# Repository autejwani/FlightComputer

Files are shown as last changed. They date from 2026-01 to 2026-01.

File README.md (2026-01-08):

# Flight Computer Firmware

This repository contains the **C++ firmware** and hardware design files for a custom **rocket flight computer** built around a Teensy development kit. The system is designed for my L1 model rocket and emphasizes low-level control and modular sensor drivers.

All firmware is written **from scratch in C++**, with no high-level sensor abstraction libraries, to allow full control over hardware configuration, timing, and data flow.

---

## System Overview

The flight computer integrates multiple sensing, estimation, and communication subsystems to estimate vehicle state and transmit telemetry during flight.

The current implementation focuses on:
- **Altitude estimation using an Extended Kalman Filter (EKF)**
- **Low-level sensor interfacing over I2C**
- **LoRa-based telemetry**
- **Modular and scalable firmware architecture**

---

## Project Structure

```text

├── Controls/
│   ├── ekf.cpp
│   └── ekf.h
│
├── Sensing/
│   ├── imu.cpp
│   ├── imu.h
│   ├── baro.cpp
│   ├── baro.h
│   ├── mag.cpp
│   └── mag.h
│
├── Utilities/
│   ├── i2c.cpp
│   └── i2c.h
│
├── LoRa/
│   ├── transmitter.cpp
│   └── receiver.cpp
│
└── main.cpp
```
## Folder Descriptions

### **Controls**
Contains control and estimation algorithms.

- **`ekf.cpp / ekf.h`**  
  Implements an **Extended Kalman Filter (EKF)** used to estimate the vehicle’s **Z-axis state (altitude)** during flight.  
  The EKF fuses inertial and barometric measurements and is designed to be expanded to full **3-axis state estimation**.

---

### **Sensing**
Contains low-level sensor drivers, each split into a header and implementation file.

- **IMU (`imu.cpp / imu.h`)**  
  Provides accelerometer and gyroscope data for motion sensing.

- **Barometer (`baro.cpp / baro.h`)**  
  Provides pressure-based altitude measurements used by the EKF.

All sensors are configured and read at the **register level**, without relying on vendor abstraction libraries.

---

### **Utilities**
Contains reusable hardware communication helpers.

- **I2C (`i2c.cpp / i2c.h`)**  
  Implements low-level I2C read/write utilities, multi-byte transactions, and device probing.  
  This layer is shared across all sensor drivers.

---

## **LoRa**
Contains long-range wireless communication code used for flight telemetry and ground station reception.

The LoRa subsystem is designed to transmit **compact, fixed-length binary packets** for reliability, low latency, and ease of parsing on resource-constrained hardware.

---

### **Telemetry Packet Format**

Each LoRa transmission consists of a **fixed 11-byte packet** with the following structure:

| Byte Index | Field | Size (bytes) | Type | Description |
|---:|---|---|---|---|
| 0 | Packet ID | 1 | `uint8_t` | Reserved for packet type / sync|
| 1–4 | Timestamp | 4 | `uint32_t`| System timestamp in **milliseconds** |
| 5–6 | Temperature | 2 | `int16_t` | Temperature in **°C × 100** (fixed-point) |
| 7–10 | Pressure | 4 | `int32_t` | Pressure in **Pascals (Pa)** |

**Total packet size:** `11 bytes`

---

### **Encoding Details**

- **Timestamp**
  - Big-endian format
  - Represents system uptime in milliseconds
  - Used for packet ordering and time correlation

- **Temperature**
  - Signed 16-bit fixed-point value  
  - Conversion:  
    ```
    temperature (°C) = int16_value / 100.0
    ```
  - Example: `2534 → 25.34 °C`

- **Pressure**
  - Signed 32-bit integer
  - Units: **Pascals (Pa)**
  - Intended for altitude calculation and EKF validation on the ground station

---

### **`transmitter.cpp`**
Packages sensor telemetry into the fixed 11-byte binary packet and transmits it over LoRa at **915 MHz**.

Responsibilities include:
- Packing sensor values into fixed-point binary fields
- Enforcing a fixed packet length
- Periodic telemetry transmission during flight

The packet structure is intentionally minimal to:
- Reduce airtime
- Improve link reliability
- Avoid dynamic memory allocation

---

### **`receiver.cpp`**
Receives and validates incoming LoRa packets on the ground station.

Responsibilities include:
- Verifying packet length (`11 bytes`)
- Parsing binary fields into native types
- Converting fixed-point values to floating-point
- Displaying telemetry via **Serial** and **OLED**

Packets with unexpected lengths are discarded to ensure data integrity.

---

### **Design**
Contains the hardware design files for the flight computer PCB.

This includes:
- PCB layout files  
- Schematics  
- Manufacturing and fabrication outputs  

These files document the **complete electrical design** of the flight computer hardware.

---

## `main.cpp`

`main.cpp` serves as the system entry point and integrates all subsystems. It:

- Initializes I2C and sensors  
- Initializes the EKF  
- Continuously reads sensor data  
- Runs the EKF update loop  
- Monitors the **Z-axis (altitude) state estimate** in real time  
- Interfaces with the LoRa telemetry system  

---

## Design Goals

- C++ firmware for embedded flight systems  
- Register-level sensor control  
- Clear separation between sensing, utilities, control, and communication  
- EKF-based state estimation  
- Reliable long-range telemetry  
- Scalable architecture for future expansion  

---

## Build Environment

- **Language:** C++  
- **Framework:** Arduino (STM32 core)  
- **Build System:** PlatformIO  
- **Target:** Custom STM32-based flight computer hardware

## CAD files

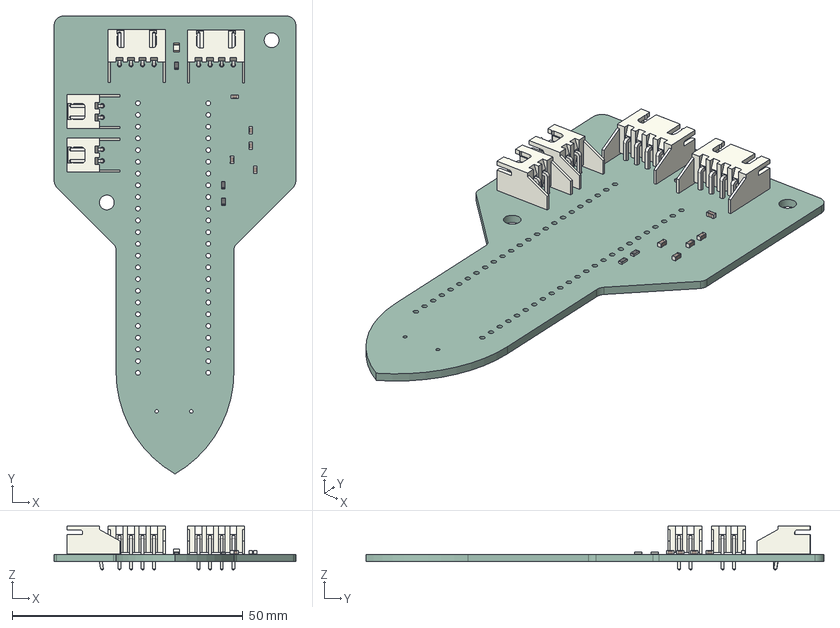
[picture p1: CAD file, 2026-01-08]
Design/AdityaFlightComputer.step
52.4 x 99.2 x 9.50 mm
JST_XH_S2B-XH-A-1_1x02_P2.50mm_Horizontal x 2
R_0603_1608Metric x 3
C_0603_1608Metric x 5
JST_XH_S4B-XH-A-1_1x04_P2.50mm_Horizontal x 2
LED_0805_2012Metric
AdityaFlightComputer_PCB

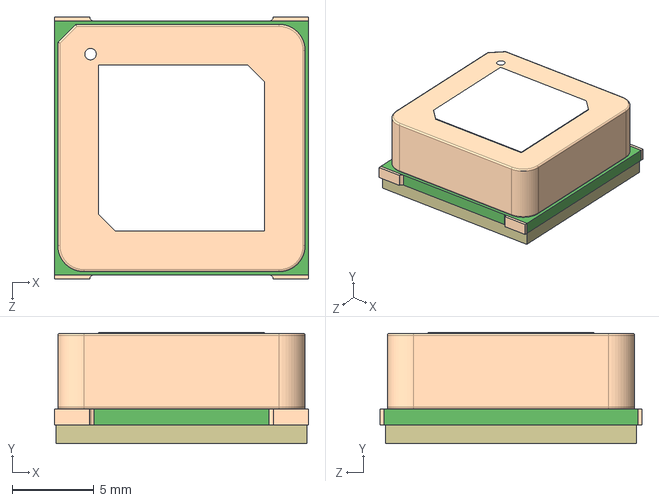
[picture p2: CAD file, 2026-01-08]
Design/Footprints/GPS/SAM-M10Q-00B.step
15.5 x 6.80 x 16.0 mm

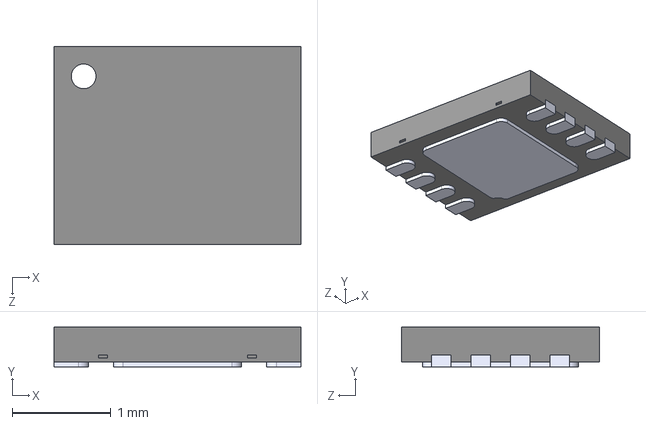
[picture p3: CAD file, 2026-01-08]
Design/Footprints/Magnetometer/MLX90397RLQ-AAA-000-SP.step
2.50 x 0.4 x 2.00 mm

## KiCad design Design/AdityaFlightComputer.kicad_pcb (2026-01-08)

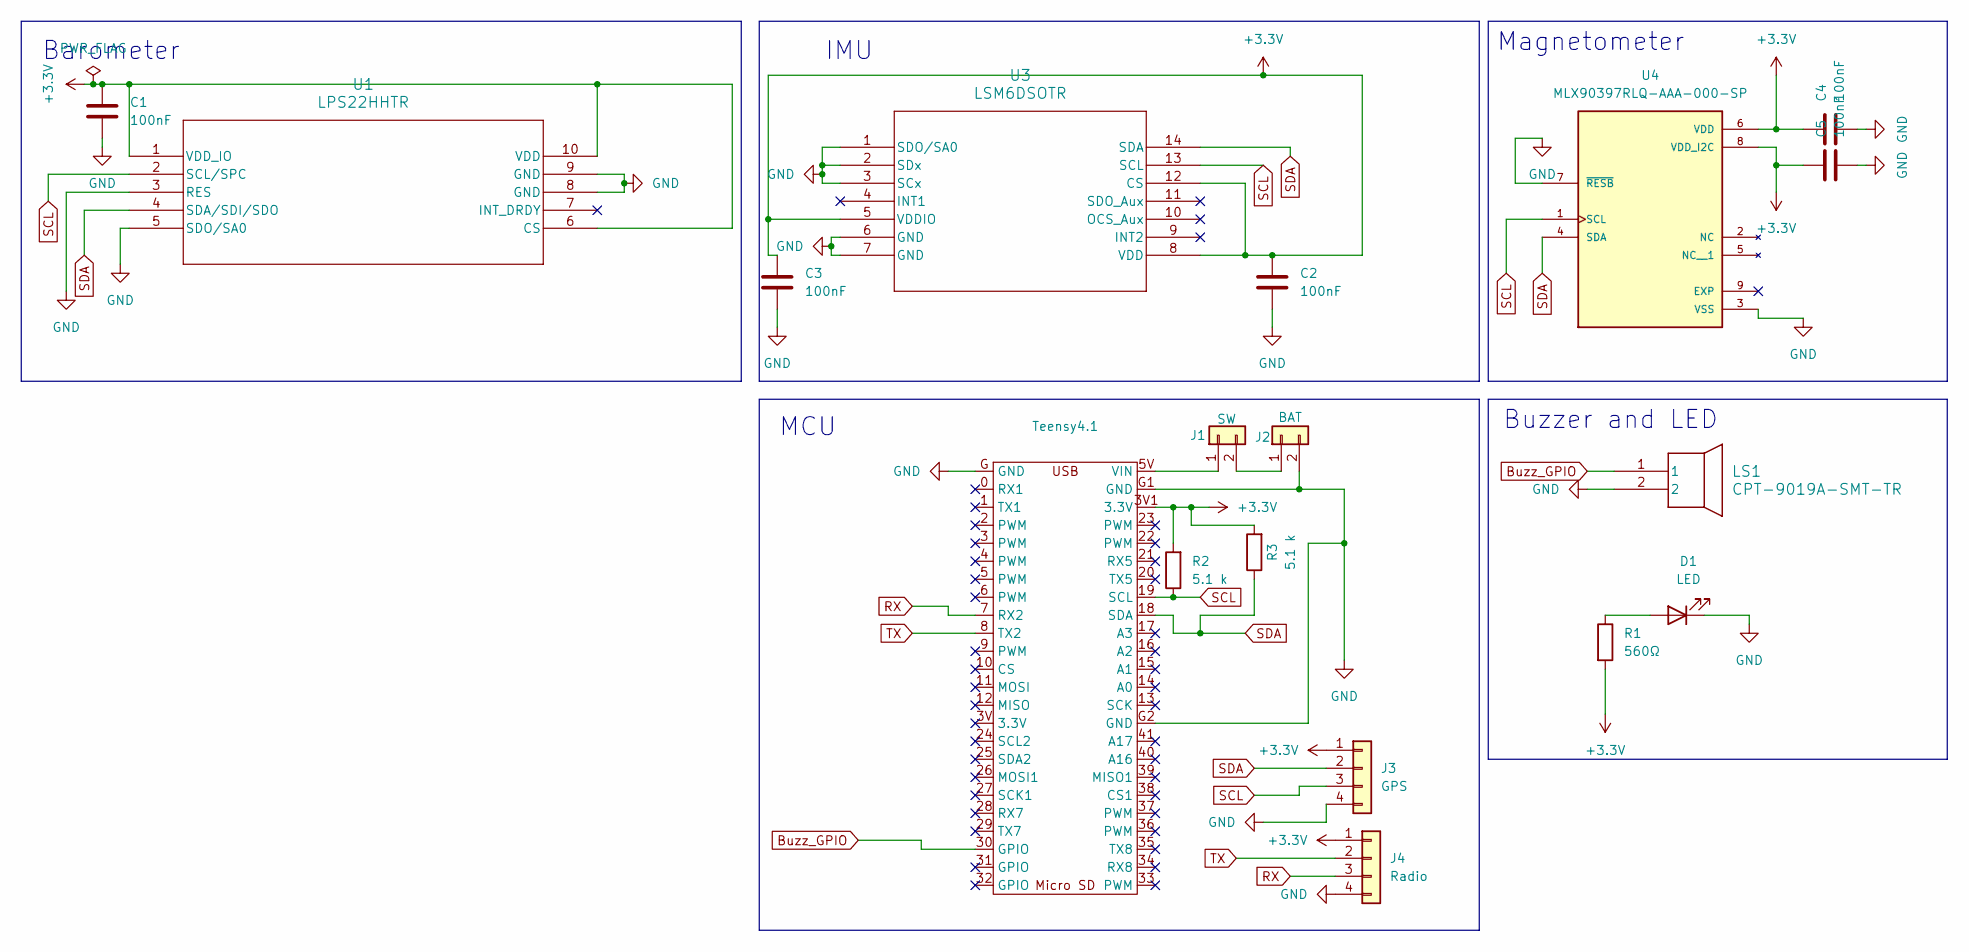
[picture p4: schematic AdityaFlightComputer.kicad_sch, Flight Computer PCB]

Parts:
C1, C2, C3, C4, C5: 100nF; C_0603_1608Metric
D1: LED; LED_0805_2012Metric
J1: SW; JST_XH_S2B-XH-A-1_1x02_P2.50mm_Horizontal
J2: BAT; JST_XH_S2B-XH-A-1_1x02_P2.50mm_Horizontal
J3: GPS; JST_XH_S4B-XH-A-1_1x04_P2.50mm_Horizontal
J4: Radio; JST_XH_S4B-XH-A-1_1x04_P2.50mm_Horizontal
LS1: CPT-9019A-SMT-TR; Adafruit_Buzzer
R1: 560Ω; R_0603_1608Metric
R2, R3: 5.1 k; R_0603_1608Metric
Teensy4.1: teensy
U1: LPS22HHTR; HLGA-10L_2X2X0P73_STM
U3: LSM6DSOTR; LGA-14L_2P5X3X0P86_STM
U4: MLX90397RLQ-AAA-000-SP; SON40P200X250X40-9N; PARTREV 002

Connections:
+3.3V: C1.1, C2.1, C3.1, C4.1, C5.1, J3.1, J4.1, R1.2, R2.2, R3.2, Teensy4.1.3V1 (3.3V), U1.1 (VDD_IO), U1.6 (CS), U1.10 (VDD), U3.5 (VDDIO), U3.8 (VDD), U3.12 (CS), U4.6 (VDD), U4.8 (VDD_I2C)
Buzz_GPIO: LS1.1, Teensy4.1.30 (GPIO)
GND: C1.2, C2.2, C3.2, C4.2, C5.2, D1.1 (K), J2.2, J3.4, J4.4, LS1.2, Teensy4.1.G (GND), Teensy4.1.G1 (GND), Teensy4.1.G2 (GND), U1.3 (RES), U1.5 (SDO/SA0), U1.8 (GND), U1.9 (GND), U3.1 (SDO/SA0), U3.2 (SDx), U3.3 (SCx), U3.6 (GND), U3.7 (GND), U4.3 (VSS), U4.7 (~RESB)
unnamed: D1.2 (A), R1.1
unnamed: J1.1, Teensy4.1.5V (VIN)
unnamed: J1.2, J2.1
RX: J4.3, Teensy4.1.7 (RX2)
SCL: J3.3, R2.1, Teensy4.1.19 (SCL), U1.2 (SCL/SPC), U3.13 (SCL), U4.1 (SCL)
SDA: J3.2, R3.1, Teensy4.1.18 (SDA), U1.4 (SDA/SDI/SDO), U3.14 (SDA), U4.4 (SDA)
TX: J4.2, Teensy4.1.8 (TX2)

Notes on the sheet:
Buzzer and LED
MCU
Magnetometer
IMU
Barometer

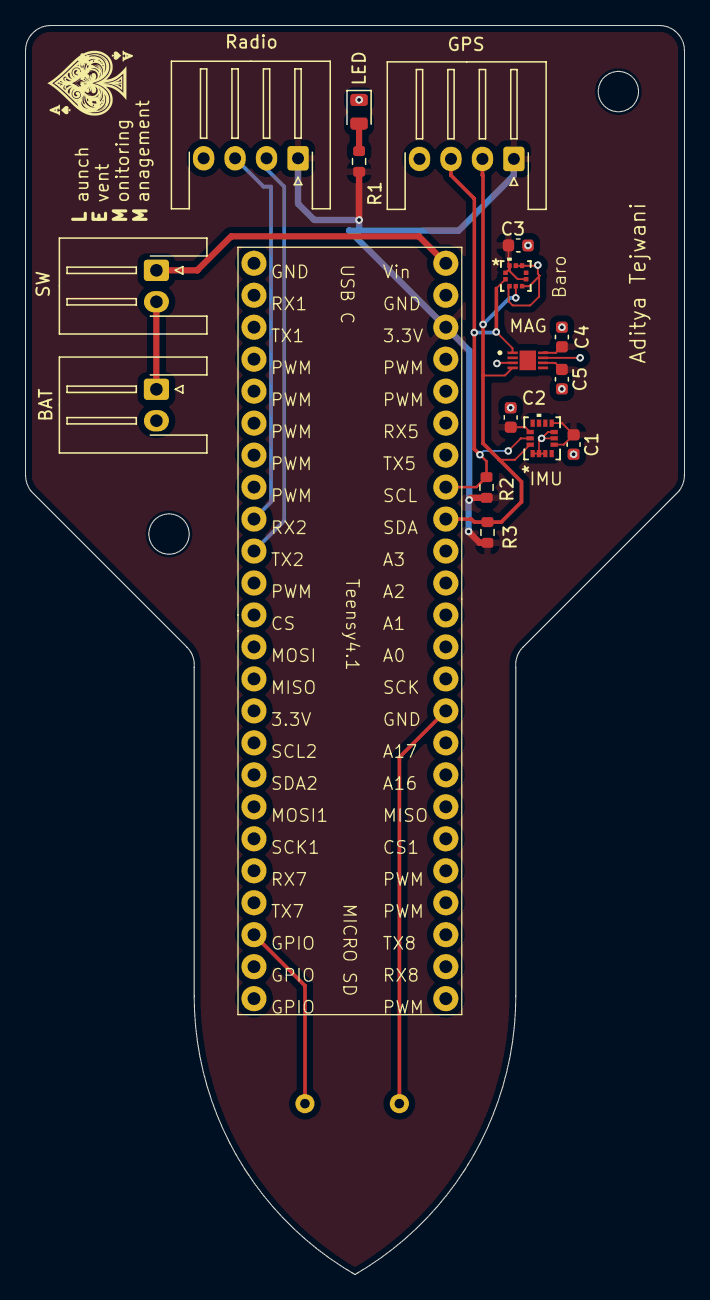
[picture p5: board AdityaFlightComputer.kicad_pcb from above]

Board: 2 copper layers, 52.4 x 99.2 mm, 18 parts (1 on the bottom side), 10 nets.

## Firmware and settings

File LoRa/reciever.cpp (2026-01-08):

#include <SPI.h>
#include <LoRa.h>
#include <Wire.h>
#include <Adafruit_GFX.h>
#include <Adafruit_SSD1306.h>


// ================= LoRa Pins =================
#define SCK 5
#define MISO 19
#define MOSI 27
#define SS 18
#define RST 14
#define DIO0 26


#define FREQ 915E6


// ================= OLED ======================
#define OLED_SDA 4
#define OLED_SCL 15
#define OLED_RST 16
#define SCREEN_WIDTH 128
#define SCREEN_HEIGHT 64


Adafruit_SSD1306 display(SCREEN_WIDTH, SCREEN_HEIGHT, &Wire, OLED_RST);


enum SystemStatus {
 SYS_OK = 0,
 SYS_LORA_FAIL
};


SystemStatus systemStatus = SYS_OK;


// ===== Buffer for received packet =====
uint8_t packet[11];


void setup() {
 Serial.begin(115200);


 // OLED reset
 pinMode(OLED_RST, OUTPUT);
 digitalWrite(OLED_RST, LOW);
 delay(20);
 digitalWrite(OLED_RST, HIGH);


 Wire.begin(OLED_SDA, OLED_SCL);
 if (!display.begin(SSD1306_SWITCHCAPVCC, 0x3C)) while (1);


 display.clearDisplay();
 display.setTextSize(1);
 display.setTextColor(SSD1306_WHITE);
 display.setCursor(0,0);
 display.println("LORA RX INIT");
 display.display();


 // LoRa init
 SPI.begin(SCK, MISO, MOSI, SS);
 LoRa.setPins(SS, RST, DIO0);


 if (!LoRa.begin(FREQ)) {
   Serial.println("LoRa init failed");
   systemStatus = SYS_LORA_FAIL;
 }


 display.clearDisplay();
 display.setCursor(0,0);
 display.println("INIT STATUS:");
 if (systemStatus == SYS_OK)
   display.println("SYS OK");
 else
   display.println("LORA FAIL");
 display.display();


 Serial.println("Receiver ready");
}


void loop() {
 if (systemStatus != SYS_OK) return;


 int packetSize = LoRa.parsePacket(11);
 Serial.println(packetSize);
 if (packetSize > 0) {
   // Make sure packet has expected length
   if (packetSize != sizeof(packet)) {
     Serial.print("Unexpected packet size: ");
     Serial.println(packetSize);
     // flush this packet
     while (LoRa.available()) LoRa.read();
     return;
   }


   // Read the full packet
   for (int i = 0; i < packetSize; i++) {
     packet[i] = LoRa.read();
   }


   // ===== Parse packet =====
   uint32_t timestamp = ((uint32_t)packet[1] << 24) |
                        ((uint32_t)packet[2] << 16) |
                        ((uint32_t)packet[3] << 8)  |
                        (uint32_t)packet[4];


   int16_t temp_fixed = ((int16_t)packet[5] << 8) |
                        (int16_t)packet[6];
   float temperature = temp_fixed / 100.0f;


   int32_t pressure = ((int32_t)packet[7] << 24) |
                      ((int32_t)packet[8] << 16) |
                      ((int32_t)packet[9] << 8)  |
                      (int32_t)packet[10];


   // ===== Serial Output =====
   Serial.println("Received Packet:");
   Serial.print("Temp(C): ");
   Serial.println(temperature,2);
   Serial.print("Pressure(Pa): ");
   Serial.println(pressure);
   Serial.print("Timestamp(ms): ");
   Serial.println(timestamp);
   Serial.println("------------------");


   // ===== OLED Output =====
   display.clearDisplay();
   display.setCursor(0,0);
   display.println("LORA RX");
   display.setCursor(0,16);
   display.print("Temp: ");
   display.print(temperature,2);
   display.println(" C");
   display.setCursor(0,28);
   display.print("Pressure: ");
   display.print(pressure);
   display.println(" Pa");
   display.setCursor(0,40);
   display.print("Time(ms): ");
   display.println(timestamp);
   display.display();
 }


 delay(50);
}

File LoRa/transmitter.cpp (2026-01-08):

#include <Arduino.h>
#include <Wire.h>
#include <SPI.h>
#include <LoRa.h>


#include <Adafruit_GFX.h>
#include <Adafruit_SSD1306.h>
#include <Adafruit_BMP085.h>


// ================= LoRa Pins =================
#define SCK   5
#define MISO  19
#define MOSI  27
#define SS    18
#define RST   14
#define DIO0  26


#define FREQ 915E6


// ================= OLED I2C ==================
#define OLED_SDA 4
#define OLED_SCL 15
#define OLED_RST 16
#define SCREEN_WIDTH 128
#define SCREEN_HEIGHT 64


// ================= BMP I2C ===================
#define BMP_SDA 21
#define BMP_SCL 22


// ================= I2C Objects ===============
TwoWire I2C_BMP = TwoWire(1);


// ================= Objects ===================
Adafruit_SSD1306 display(SCREEN_WIDTH, SCREEN_HEIGHT, &Wire, OLED_RST);
Adafruit_BMP085 bmp;


// ================= System Status =============
enum SystemStatus {
 SYS_OK = 0,
 SYS_BMP_FAIL,
 SYS_LORA_FAIL
};


SystemStatus systemStatus = SYS_OK;


// ================= Timing ====================
unsigned long lastTx = 0;
const unsigned long txInterval = 10000;


// ================= Packet ====================
uint8_t packet[11];


void setup() {
 Serial.begin(115200);


 // ===== OLED RESET =====
 pinMode(OLED_RST, OUTPUT);
 digitalWrite(OLED_RST, LOW);
 delay(20);
 digitalWrite(OLED_RST, HIGH);


 // ===== OLED I2C INIT =====
 Wire.begin(OLED_SDA, OLED_SCL);


 // ===== BMP I2C INIT =====
 I2C_BMP.begin(BMP_SDA, BMP_SCL);
 I2C_BMP.setClock(100000); // BMP-safe speed


 // ===== OLED INIT =====
 if (!display.begin(SSD1306_SWITCHCAPVCC, 0x3C)) {
   while (1);
 }


 display.clearDisplay();
 display.setTextSize(1);
 display.setTextColor(SSD1306_WHITE);
 display.setCursor(0, 0);
 display.println("LORA TX INIT");
 display.display();


 // ===== BMP INIT (ON Wire1) =====
 if (!bmp.begin(BMP085_STANDARD, &I2C_BMP)) {
   systemStatus = SYS_BMP_FAIL;
 }


 // ===== LORA INIT =====
 SPI.begin(SCK, MISO, MOSI, SS);
 LoRa.setPins(SS, RST, DIO0);


 if (!LoRa.begin(FREQ)) {
   systemStatus = SYS_LORA_FAIL;
 }


 // ===== STATUS DISPLAY =====
 display.clearDisplay();
 display.setCursor(0, 0);
 display.println("INIT STATUS:");


 if (systemStatus == SYS_OK)
   display.println("SYS OK");
 else if (systemStatus == SYS_BMP_FAIL)
   display.println("BMP FAIL");
 else if (systemStatus == SYS_LORA_FAIL)
   display.println("LORA FAIL");


 display.display();
 delay(2000);
}


void loop() {
 unsigned long now = millis();
 if (now - lastTx < txInterval) return;
 lastTx = now;


 display.clearDisplay();
 display.setCursor(0, 0);
 display.println("LORA TX");


 if (systemStatus != SYS_OK) {
   display.setCursor(0, 16);
   display.println("SYSTEM ERROR");
   display.display();
   return;
 }


 // ===== Read Sensors (BMP on Wire1) =====
 float temp_c = bmp.readTemperature();
 int32_t pressure = bmp.readPressure();
 int16_t temp_fixed = (int16_t)(temp_c * 100.0f);
 uint32_t timestamp = millis();


 // ===== Build Packet =====
 packet[0] = 10;


 packet[1]  = (timestamp >> 24) & 0xFF;
 packet[2]  = (timestamp >> 16) & 0xFF;
 packet[3]  = (timestamp >> 8)  & 0xFF;
 packet[4]  = timestamp & 0xFF;


 packet[5]  = (temp_fixed >> 8) & 0xFF;
 packet[6]  = temp_fixed & 0xFF;


 packet[7]  = (pressure >> 24) & 0xFF;
 packet[8]  = (pressure >> 16) & 0xFF;
 packet[9]  = (pressure >> 8)  & 0xFF;
 packet[10] = pressure & 0xFF;


 // ===== Transmit =====
 LoRa.beginPacket();
 LoRa.write(packet, sizeof(packet));
 LoRa.endPacket();


 // ===== OLED DISPLAY =====
 display.setCursor(0, 16);
 display.print("T: ");
 display.print(temp_c, 2);
 display.println(" C");


 display.setCursor(0, 28);
 display.print("P: ");
 display.print(pressure);
 display.println(" Pa");


 display.setCursor(0, 40);
 display.print("t(ms): ");
 display.println(timestamp);


 display.display();
}
